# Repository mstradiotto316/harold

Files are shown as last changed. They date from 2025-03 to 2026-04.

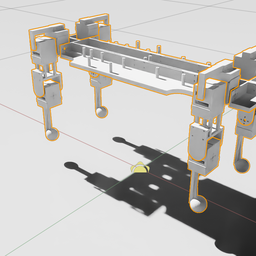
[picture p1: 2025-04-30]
part_files/V4/.thumbs/256x256/harold_5.usd.png

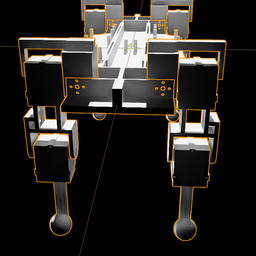
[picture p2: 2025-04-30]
part_files/V4/.thumbs/256x256/harold_2.usd.png

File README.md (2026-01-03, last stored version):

# Harold Quadruped Robot

This repository contains the code for the Harold quadruped robot, a small legged robot platform for reinforcement learning research and experimentation.

## TODO

1. Make sure the new robot meets this setup
https://docs.isaacsim.omniverse.nvidia.com/latest/isaac_lab_tutorials/tutorial_instanceable_assets.html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
2. Fix component mounts on the next iteration of the chassis
3. Set the base servo ID to 0 instead of 1 (it's too difficult to disassemble it all again to fix this)

## Isaac Sim & Isaac Lab
NOTE: This is meant to be used on Linux Ubuntu
NOTE: YOU MUST INSTALL ISAAC SIM AND ISAAC LAB FIRST
https://isaac-sim.github.io/IsaacLab/main/source/setup/installation/binaries_installation.html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

1. Make sure you install the project:
    python -m pip install -e harold_isaac_lab/source/harold_isaac_lab

2. To see the available tasks use:
    python harold_isaac_lab/scripts/list_envs.py

3. To run training (recommended):
    activate the virtual environment:
    source ~/Desktop/env_isaaclab/bin/activate

    run the default flat-terrain training:
    python scripts/harold.py train

    optional task selection:
    python scripts/harold.py train --task rough

    optional mode selection:
    python scripts/harold.py train --mode scripted

    advanced/manual (avoid for agents):
    python harold_isaac_lab/scripts/skrl/train.py --task=Template-Harold-Direct-flat-terrain-v0 --num_envs 8192 --headless --video --video_length 250 --video_interval 3200

4. Launch Tensorboard to view training progress:
python3 -m tensorboard.main --logdir logs/

## Repository Structure 

- `firmware/`: Arduino code for the robot
  - `robot_controller/`: Main servo controller for the robot
  - `servo_calibration/`: Servo calibration utility
  - `joint_test/`: Test individual robot joints

- `policy/`: Neural network policy for robot control
  - `harold_policy.onnx`: ONNX model for the control policy
  - `action_config.pt`: Configuration for action scaling
  - `observations_playback_test.py`: Test policy with recorded observations

- `sensors/`: Code for interfacing with sensors
  - `imu_reader.py`: Class for MPU6050 IMU sensor integration
  - `smbus_example.py`: Example for I2C communication

- `tools/`: Utility scripts
  - `verify_policy.py`: Verify the ONNX policy model
  - `test_imu.py`: Test the IMU sensor
  - `edit_action_config.py`: Tool to edit action configuration

- `simulation_files/` & `pushup_simulation_files/`: Simulation environments
  - Contains simulation code for training and testing the robot

- `simulation_logs/`: Log files from simulation for playback testing
  - `observations.log`: Recorded sensor observations
  - `actions.log`: Recorded policy actions
  - `processed_actions.log`: Actions processed for deployment

## Hardware Components

### Computing
- **Jetson Nano**: Main computing platform running the neural network policy
  - Communicates with IMU via I2C bus 1
  - Connects to Arduino via USB (typically /dev/ttyACM0)

### Sensors
- **MPU6050 IMU**: 6-axis inertial measurement unit
  - I2C address: 0x68
  - Provides acceleration and gyroscope measurements
  - Connected to I2C bus 1 on Jetson Nano

### Actuators
- **ESP32 Servo Controller**: Motor controller board
  - Serial communication at 115200 baud rate
  - Runs control loop at 200Hz (5ms intervals)

- **FeeTech STS3215 Servo Motors**: For quadruped locomotion
  - 3 servos per leg (shoulder, thigh, calf)
  - Safety features include emergency shutdown and position limits

## Joint Configuration

The robot's joint configuration matches the simulation directly:

1. **Joint Order**:
   - 0: Front Left Shoulder
   - 1: Front Right Shoulder
   - 2: Back Left Shoulder
   - 3: Back Right Shoulder
   - 4: Front Left Thigh
   - 5: Front Right Thigh
   - 6: Back Left Thigh
   - 7: Back Right Thigh
   - 8: Front Left Knee
   - 9: Front Right Knee
   - 10: Back Left Knee
   - 11: Back Right Knee

2. **Servo Direction**:
   - Shoulders: Positive positions move upward from center, negative positions move downward
   - Thighs and Knees: Positive positions move toward the front of the robot, negative positions move toward the rear

This configuration ensures that the real robot's movements directly correspond to the simulation, with no need for joint remapping or direction inversions.

## Development Environment

### Arduino IDE

Due to limitations on the Jetson Nano, we are forced to use an older ARM specific version of the Arduino software:

*   Legacy IDE (1.8.19) Linux Arm 64 Bit

**Important Notes for this Arduino Environment:**

*   **Unavailable Functions:** Be aware that some standard C/C++ library functions might be missing. For example, `strtof` (string-to-float with error checking) is unavailable. Use alternatives like `atof` (standard C string-to-float), keeping in mind its limitations (e.g., less robust error reporting).
*   **Code Structure:** This environment may be stricter regarding code structure than newer IDEs. To avoid `"not declared in this scope"` errors, ensure proper C/C++ ordering: Place all `#include` directives, `#define` constants, global variable declarations, and forward function declarations (prototypes) *before* the `setup()` and `loop()` functions. Define helper functions *after* `loop()`. Do not rely solely on the IDE's automatic function prototyping.

## Usage

### Running with Live IMU Data

To run the robot with live IMU sensor data:

```bash
python3 policy/robot_controller.py [--serial_port PORT]
```

### Running with Recorded Observations

To run the robot using pre-recorded observation logs from simulation:

```bash
python3 policy/observations_playback_test.py [--obs_log_file PATH] [--serial_port PORT] [--loop]
```

Options:
- `--obs_log_file PATH`: Specify a custom observation log file (default: simulation_logs/observations.log)
- `--serial_port PORT`: Specify a custom serial port (default: /dev/ttyACM0)
- `--loop`: Continuously loop the observation log file

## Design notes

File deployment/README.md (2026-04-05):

# Harold Deployment - Raspberry Pi 5

Real-time inference for Harold quadruped robot using either open-loop CPG or direct RL policy control.

## Architecture

```
RPi 5 (inference + CPG) <--USB Serial 115200--> ESP32 (servo control) <--1Mbps--> 12 Servos
         |
         | I2C
         v
     MPU6050 (IMU)
```

## Quick Start

```bash
# Install dependencies
pip install -r requirements.txt

# Run controller (robot must be connected)
python inference/harold_controller.py
```

## Components

| Component | Description |
|---|---|
| `policy/harold_policy.onnx` | Exported neural network (48D -> 12D) |
| `policy/policy_metadata.json` | Normalization stats + joint config |
| `inference/harold_controller.py` | Main 20 Hz control loop |
| `inference/cpg_generator.py` | CPG trajectory generator |
| `common/cpg_math.py` | Shared CPG math kernel (sim + hardware) |
| `inference/observation_builder.py` | IMU + servo -> 48D observation |
| `inference/action_converter.py` | Policy output -> servo commands |
| `drivers/imu_reader_rpi5.py` | MPU6050 I2C driver |
| `drivers/esp32_serial.py` | ESP32 serial wrapper |

## Control Loop (20 Hz)

1. Compute CPG base trajectory from time (CPG-only mode)
2. Build 48D observation from IMU + servo feedback (policy mode)
3. Run ONNX inference -> 12D action (policy mode)
4. Convert targets to hardware convention
5. Send to ESP32 via serial

## Safety Features

- 250ms watchdog timeout
- Joint angle limits (conservative)
- Load monitoring (>90% = emergency stop)
- Keyboard interrupt = safe stance

## Configuration

- `config/hardware.yaml` - Servo IDs, signs, limits
- `config/cpg.yaml` - CPG parameters (matches simulation)
- `config/stance.yaml` - Canonical ready stance (shared across hardware + sim)

Note: `policy/policy_metadata.json` captures training-time defaults; do not edit it for stance changes.

### Joint Sign Convention

- Shoulders are not mirrored at the high-level command/observation layer. Positive shoulder motion should mean the same thing on every leg.
- Thighs and calves are inverted between RL convention and hardware convention.
- Right-side servo mirroring is handled by `config/hardware.yaml` `direction` and the ESP32 firmware `DIR_TABLE`, not by flipping shoulder `joint_sign`.
- `inference.harold_controller` rejects startup if exported metadata `joint_sign` does not match `config/hardware.yaml`.

## Testing

```bash
# Test IMU
python tests/test_imu.py

# Test ESP32 communication
python tests/test_esp32.py

# Test inference (no hardware)
python tests/test_inference.py
```

## Diagnostics

- Session CSVs now flush every row by default to survive abrupt resets.
- Controller exceptions write to `logs/controller_diagnostics.log` with throttling + USB state.
- To persist system logs across reboots, run `scripts/enable_persistent_journal.sh` on the Pi (requires sudo).

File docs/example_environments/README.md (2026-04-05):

# Isaac Lab Example Environments

Technical breakdowns of every quadruped locomotion environment in Isaac Lab. Each document covers the robot specs, observation/action spaces, full reward structure with weights, command ranges, domain randomization, training config, and relevance to Harold.

These are reference implementations that Harold's training is based on. Use them to compare reward terms, thresholds, and scaling when debugging or tuning Harold's config.

## Manager-Based Environments

| Robot | Terrain | File | Gym ID |
|---|---|---|---|
| Boston Dynamics Spot | Flat | [spot_flat.md](spot_flat.md) | `Isaac-Velocity-Flat-Spot-v0` |
| Unitree Go2 | Flat | [go2_flat.md](go2_flat.md) | `Isaac-Velocity-Flat-Unitree-Go2-v0` |
| Unitree Go2 | Rough | [go2_rough.md](go2_rough.md) | `Isaac-Velocity-Rough-Unitree-Go2-v0` |
| Unitree Go1 | Flat | [go1_flat.md](go1_flat.md) | `Isaac-Velocity-Flat-Unitree-Go1-v0` |
| Unitree Go1 | Rough | [go1_rough.md](go1_rough.md) | `Isaac-Velocity-Rough-Unitree-Go1-v0` |
| Unitree A1 | Flat | [a1_flat.md](a1_flat.md) | `Isaac-Velocity-Flat-Unitree-A1-v0` |
| ANYbotics ANYmal D | Flat | [anymal_d_flat.md](anymal_d_flat.md) | `Isaac-Velocity-Flat-Anymal-D-v0` |
| ANYbotics ANYmal D | Rough | [anymal_d_rough.md](anymal_d_rough.md) | `Isaac-Velocity-Rough-Anymal-D-v0` |
| ANYbotics ANYmal B | Flat | [anymal_b_flat.md](anymal_b_flat.md) | `Isaac-Velocity-Flat-Anymal-B-v0` |
| ANYbotics ANYmal B | Rough | [anymal_b_rough.md](anymal_b_rough.md) | `Isaac-Velocity-Rough-Anymal-B-v0` |

## Direct Environments

| Robot | Terrain | File | Gym ID |
|---|---|---|---|
| ANYbotics ANYmal C | Flat/Rough | [anymal_c_direct.md](anymal_c_direct.md) | `Isaac-Velocity-Flat-Anymal-C-Direct-v0` |

**ANYmal C Direct is the most relevant reference for Harold** — it uses the same direct environment architecture (not manager-based) and reveals important porting considerations like manual `step_dt` multiplication on rewards.

## Robot Size Comparison

| Robot | Mass | Leg Length | DOF | Notes |
|---|---|---|-----|---|
| **Harold** | **2 kg** | **~0.15 m** | **12** | **Our robot** |
| Unitree A1 | ~12 kg | ~0.25 m | 12 | Closest in size |
| Unitree Go1 | ~12 kg | ~0.25 m | 12 | Similar to A1 |
| Unitree Go2 | ~15 kg | ~0.3 m | 12 | Mid-size |
| BD Spot | ~32 kg | ~0.5 m | 12 | Our reward source |
| ANYmal B | ~30 kg | ~0.4 m | 12 | Large |
| ANYmal C | ~50 kg | ~0.55 m | 12 | Large, direct env |
| ANYmal D | ~50 kg | ~0.55 m | 12 | Large |

Harold is significantly smaller than all reference robots. Key scaling considerations:
- **Velocity commands**: Scale down proportionally to leg length (Froude scaling)
- **Velocity thresholds**: Must be lowered for Harold's achievable speeds
- **Air time / gait cadence**: Smaller animals step faster
- **Foot clearance**: Scale to ~20% of leg length
- **Domain randomization**: Mass perturbations, push forces, etc. must be proportional to body mass
- **Reward weights**: Torque and force penalties may need rebalancing for smaller actuators

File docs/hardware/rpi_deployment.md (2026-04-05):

# Harold Deployment - Raspberry Pi 5

Real-time inference for Harold quadruped robot (open-loop CPG or direct RL policy depending on mode).

## Architecture

```
RPi 5 (inference + CPG) <--USB Serial 115200--> ESP32 (servo control) <--1Mbps--> 12 Servos
         |
         | I2C
         v
     MPU6050 (IMU)
```

## Quick Start

Use system `python3` on the Pi (no virtualenv required).

```bash
# Install dependencies
python3 -m pip install -r deployment/requirements.txt

# Run controller (robot must be connected)
python3 -m inference.harold_controller
```

## Syncing Runtime from Desktop

The Pi runtime is a git checkout of this repo. Sync from the desktop before hardware tests:

```bash
# On the desktop after edits
git add -A
git commit -m "Describe changes"
git push

# On the Pi before tests
git status -sb     # must be clean
git pull --ff-only
```

Avoid editing runtime code on the Pi. If a hotfix is unavoidable, commit it on the Pi,
push, and then pull it on the desktop to keep both repos in sync.

## Components

Paths below are relative to the deployment root (typically `<repo-root>/deployment`, e.g. `/home/pi/harold/deployment`).

| Component | Description |
|---|---|
| `policy/harold_policy.onnx` | Exported neural network (observation -> 12D actions) |
| `policy/policy_metadata.json` | Normalization stats + joint config (if applicable) |
| `inference/harold_controller.py` | Main policy-rate control loop |
| `inference/cpg_generator.py` | CPG trajectory generator |
| `common/cpg_math.py` | Shared CPG math kernel (sim + hardware) |
| `inference/observation_builder.py` | IMU + servo -> 48D observation |
| `inference/action_converter.py` | Policy output -> servo commands |
| `drivers/imu_reader_rpi5.py` | MPU6050 I2C driver |
| `drivers/esp32_serial.py` | ESP32 serial wrapper |

## Control Loop (policy rate)

1. Compute CPG base trajectory from time (CPG-only mode)
2. Build 48D observation from IMU + servo feedback (policy mode)
3. Run ONNX inference (normalization may be baked into the export; verify before adding preprocessing)
4. Convert targets to hardware convention
5. Send to ESP32 via serial

## Safety Features

- Watchdog timeout (configured in firmware)
- Joint angle limits (conservative, configured in runtime)
- Load monitoring with emergency stop (threshold configured in runtime)
- Keyboard interrupt = safe stance

## Configuration

- `config/hardware.yaml` - Servo IDs, signs, limits
- `config/cpg.yaml` - CPG parameters (matches simulation)
- `config/stance.yaml` - Canonical ready stance (shared across hardware + sim)

Note: `policy/policy_metadata.json` captures training-time defaults; do not edit it for stance changes.

### Joint Sign Convention

- High-level shoulder semantics are the same on all four legs. Do not mirror FR/BR shoulders in policy space.
- Thigh and calf joints are sign-inverted between RL convention and hardware convention.
- Right-side servo mounting is handled separately by `config/hardware.yaml` `direction` values and the ESP32 firmware `DIR_TABLE`.
- Controller startup treats `config/hardware.yaml` as the source of truth and rejects exported metadata whose `joint_sign` disagrees with it.

## Testing

```bash
# Test IMU
python tests/test_imu.py

# Test ESP32 communication
python tests/test_esp32.py

# Test inference (no hardware)
python tests/test_inference.py
```

## Diagnostics

- Session CSVs now flush every row by default to survive abrupt resets.
- Controller exceptions write to `logs/controller_diagnostics.log` with throttling + USB state.
- To persist system logs across reboots, run `scripts/enable_persistent_journal.sh` on the Pi (requires sudo).

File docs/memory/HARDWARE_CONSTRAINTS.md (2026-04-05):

# Hardware Constraints for Sim-to-Real Transfer

## Purpose

This document provides **REAL-WORLD CONSTRAINTS** that experimentation agents MUST consider when proposing configuration changes. Simulation parameters should remain within these bounds for successful hardware deployment.

**Read this before modifying**: `effort_limit`, `stiffness`, `damping`, joint limits, or control rates.

---

## Servo Specifications (FeeTech ST3215)

Source: `docs/hardware/servos/ST3215_Servo.pdf`, `docs/hardware/servos/Communication_Protocol_User_Manual_EN.pdf`

### Torque & Power

| Parameter | Real Hardware | Simulation | Status |
|---|---|---|---|
| **Max Torque** | 30 kg·cm (2.94 Nm) @12V | 2.8 Nm | 95% of max |
| Idle Current | 180 mA | N/A | - |
| Stall Current | 2.7 A | N/A | - |
| Voltage | 6-12.6V (12V recommended) | N/A | - |

**Note**: Simulation uses 2.8 Nm effort limit (95% of hardware max). Session 21 discovered that stiffness (not just effort limit) was the critical factor - increased from 200 to 1200 for realistic servo tracking.

### Position & Speed

| Parameter | Real Hardware | Simulation | Status |
|---|---|---|---|
| Resolution | 4096 steps/360° (0.088°/step) | Continuous | OK |
| Max Speed | 45 RPM (270°/s = 4.71 rad/s) @12V | Limited by PD | Verify on hardware |
| Control Rate | Position commands @1 Mbps bus | 20 Hz policy | OK |

### Joint Limits (Mechanical)

| Joint | Min | Max | Simulation | Status |
|---|-----|-----|---|---|
| Shoulders | -30° (-0.5236 rad) | +30° (+0.5236 rad) | ±0.5236 rad | Matched |
| Thighs | -90° (-1.5708 rad) | +90° (+1.5708 rad) | ±1.5708 rad | Matched |
| Calves | -90° (-1.5708 rad) | +90° (+1.5708 rad) | ±1.5708 rad | Matched |

**WARNING**: Joint limits are mechanical stops. Exceeding them in sim will not transfer to hardware - the servo will hit physical limits and potentially damage the robot.

---

## Controller (ESP32)

| Parameter | Value | Notes |
|---|---|---|
| Control loop | ~200 Hz | 5 ms intervals |
| Servo bus | Serial1 @ 1 Mbps | TTL half-duplex |
| USB telemetry | 115200 baud | To host PC |
| Watchdog | 250 ms timeout | E-stop on timeout |

---

## IMU (MPU6050)

| Parameter | Value | Notes |
|---|---|---|
| Type | 6-axis (3 accel + 3 gyro) | |
| I2C address | 0x68 | |
| Sample rate | Up to 200 Hz | Matches control loop |
| Noise (angular velocity) | ~0.01 rad/s | Sim uses this for DR |
| Noise (gravity projection) | ~0.05 | Sim uses this for DR |

---

## Physical Robot

| Parameter | Value | Source |
|---|---|---|
| Total mass | ~2.0 kg | Measured |
| Body dimensions | ~20×15×8 cm | CAD model |
| Ground clearance (standing) | ~18 cm | Measured |
| Spawn height (sim) | 0.24 m | harold.py config |
| Target height (walking) | 0.275 m | GaitCfg |

---

## Safe Parameter Ranges for Experiments

### DO NOT EXCEED (Hardware Limits)

| Parameter | Current | Max Safe | Reason |
|---|---|---|---|
| `effort_limit` | 2.8 Nm | 2.94 Nm | Currently at 95% of hardware max |
| `stiffness` | 1200 | TBD | Session 21: Higher values needed for sim accuracy |
| `damping` | 50 | TBD | Session 21: Lower ratio for responsiveness |
| `action_scale` | 0.5 | 1.0 | Larger may hit joint limits with some poses |

**Session 21 Discovery**: Original stiffness=200 was FAR too low. Servos couldn't extend legs under load. Real robot does pushups fine, so sim was inaccurate. Stiffness=1200 with damping=50 matches real servo behavior. Sim-to-real testing needed to validate these values on hardware.

### MUST PRESERVE (Sim-to-Real Critical)

| Parameter | Required Value | Reason |
|---|---|---|
| Joint limits (shoulders) | ±30° (±0.5236 rad) | Mechanical stops |
| Joint limits (thighs/calves) | ±90° (±1.5708 rad) | Mechanical stops |
| Control rate | 20 Hz policy | Matches deployment pipeline |
| Joint order | [FL, FR, BL, BR] × [shoulder, thigh, calf] | Matches firmware |
| Sign convention | Thighs/calves inverted | See `action_config.json` |

### MAY TUNE FREELY (No Hardware Impact)

| Parameter | Typical Range | Notes |
|---|---|---|
| Reward weights | Any | Pure learning signal |
| `action_filter_beta` | 0.1-0.5 | Smoothing preference |
| Termination thresholds | Any | Training curriculum |
| Domain randomization ranges | Any | Robustness tuning |
| `height_reward`, `forward_reward` etc. | Any | Reward shaping |
| `low_height_penalty`, `low_height_threshold` | Any | Training signal |

---

## Servo Communication Protocol

From `docs/hardware/servos/Communication_Protocol_User_Manual_EN.pdf`:

- **Packet format**: `0xFF 0xFF` + ID + Length + Instruction + Parameters + Checksum
- **ID range**: 0-253 (Harold uses IDs 1-12)
- **Broadcast ID**: 254 (0xFE) for simultaneous control
- **Instructions**: PING (0x01), READ (0x02), WRITE (0x03), SYNC WRITE (0x83)
- **Feedback available**: Position, Speed, Load, Voltage, Temperature, Current

---

## Deployment Mapping

### Joint Order (RL → Firmware)

```
RL Policy Output:  [FL_sh, FR_sh, BL_sh, BR_sh, FL_th, FR_th, BL_th, BR_th, FL_ca, FR_ca, BL_ca, BR_ca]
Servo IDs:         [1,     4,     7,     10,    2,     5,     8,     11,    3,     6,     9,     12]
```

### Sign Convention

| Joint Type | RL → Hardware | Notes |
|---|---|---|
| Shoulders | +1.0 (same) | Direct mapping |
| Thighs | -1.0 (inverted) | Servo mounting |
| Calves | -1.0 (inverted) | Servo mounting |

### Position Conversion

```
servo_units = 2047 + direction * (degrees * 4096 / 360)
```

Where `direction` is +1 or -1 per the sign convention table.

---

## Servo Control Registers (ST3215)

### Critical for Backlash Mitigation

| Register | Address | Purpose | Optimal Value | Notes |
|---|---|---|---|---|
| **ACC** | 41 | Acceleration profile | **150** | 0=slowest (soft), 150=fastest (instant) |
| TORQUE_ENABLE | 40 | Enable torque | 1 | 0=limp, 1=active |
| MODE | 33 | Operating mode | 0 | 0=servo (position), 1=motor (velocity) |
| CW_DEAD | 26 | Clockwise dead zone | 1 | Minimum possible |
| CCW_DEAD | 27 | Counter-clockwise dead zone | 1 | Minimum possible |

**CRITICAL**: The ST3215's "built-in acceleration start-stop function makes the action softer" (from datasheet). For backlash systems, this is WRONG - we want **maximum acceleration** (ACC=150) for instant "bang-bang" control to cross the dead zone as fast as possible.

### WritePosEx Parameters

```cpp
st.WritePosEx(ID, Position, Speed, ACC);
// Speed: 0 = max speed (no limit), higher = specific speed in steps/sec
// ACC: 0 = slowest (soft ramp), 150 = fastest (instant)
```

---

## Training Workstation

| Component | Spec |
|---|---|
| GPU | NVIDIA GeForce RTX 4080 (16 GB VRAM) |
| RAM | 63 GB |
| CPU | Intel Core i7-8700K @ 3.70GHz |

### Training Throughput (benchmarked 2026-03-19)

**Two-phase approach**: Training runs without video at high envs; video captured post-hoc via `harold record` (~30-45s from best checkpoint at 1 env). This removes video as the RAM bottleneck.

| Envs | it/s | Samples/s | GPU | RAM | Status |
|---|---|---|-----|-----|---|
|  1024 | 18.1 | 0.45M |  6.2 GB |  8.6 GB | OK |
|  4096 | 16.0 | 1.58M |  7.2 GB |  9.3 GB | OK |
|  8192 | 11.5 | 2.26M |  8.3 GB | 10.3 GB | OK |
| 16384 |  7.3 | 2.88M | 10.3 GB | 12.3 GB | Direct-env only (standing trap at this scale) |
| 24576 |  5.4 | 3.18M | 12.3 GB | 14.6 GB | Direct-env only |

**Default: 2048 envs** (manager-based). OOMs at 4096 with ManagerBasedRLEnv on RTX 4080. Benchmark above is for direct-env (deprecated).

---

## References

- Servo datasheet: `docs/hardware/servos/ST3215_Servo.pdf`
- Communication protocol: `docs/hardware/servos/Communication_Protocol_User_Manual_EN.pdf`
- Register map: `docs/hardware/servos/ST3215_memory_register_map_EN.xls`
- Calibration guide: `docs/hardware/calibration_checklist.md`
- Deployment runtime: `docs/hardware/rpi_deployment.md`
- Action config: `deployment_artifacts/terrain_62/action_config.json`

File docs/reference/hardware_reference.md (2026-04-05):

# Hardware Reference (Robot + RPi)

This file is a technical reference for hardware operation. Use `AGENTS.md` for workflows and `docs/memory/CONTEXT.md` for current network details.

## Core hardware stack

- Raspberry Pi 5 runs policy inference and the 20 Hz control loop.
- ESP32 handles the servo bus control loop and safety watchdog.
- FeeTech STS3215 servos provide joint actuation.
- MPU6050 IMU provides inertial measurements.

For exact limits, servo specs, and safe ranges, see `docs/memory/HARDWARE_CONSTRAINTS.md`.

## Runtime layout (RPi)

Confirm repo and runtime paths in `docs/memory/CONTEXT.md` before running commands.
Runtime root is the repo’s `deployment/` directory (e.g. `/home/pi/harold/deployment`).

- Repo path (git checkout): see `docs/memory/CONTEXT.md`
- Runtime root: `<runtime-root>` (see `docs/memory/CONTEXT.md`)
- Main controller: `<runtime-root>/inference/harold_controller.py`
- Policy: `<runtime-root>/policy/harold_policy.onnx`
- Configs: `<runtime-root>/config/`
- Logs: `<runtime-root>/logs/`

## Syncing code to the Pi

The Pi runtime is a git checkout of this repo. Sync from the desktop with:

```bash
# On the desktop after edits
git add -A
git commit -m "Describe changes"
git push

# On the Pi before tests
git status -sb     # must be clean
git pull --ff-only
```

Do not edit runtime code directly on the Pi. If a hotfix is unavoidable, commit it on the Pi,
push, and then pull it on the desktop to keep both repos in sync.

## SSH access

Network addresses and credentials are tracked in `docs/memory/CONTEXT.md`.

```bash
ssh pi@<ip-or-host>
```

## Network configuration

Current IPs, hostnames, and WiFi details are maintained in `docs/memory/CONTEXT.md`.

## Service management (RPi)

```bash
sudo systemctl status harold
sudo systemctl restart harold
sudo systemctl stop harold
sudo systemctl start harold
sudo systemctl disable harold
sudo systemctl enable harold
```

## Manual controller run (RPi)

Use system `python3` on the Pi (no virtualenv required).

```bash
# Stop the service first
sudo systemctl stop harold

# Run controller manually
cd <runtime-root>
python3 -m inference.harold_controller
```

For CPG-only or scripted gait tests, see `AGENTS.md` and `docs/memory/NEXT_STEPS.md`.

## Firmware flashing (ESP32)

The ESP32 must run the streaming control firmware for the Pi to communicate with it.

```bash
# Install arduino-cli (one-time)
curl -fsSL https://raw.githubusercontent.com/arduino/arduino-cli/master/install.sh | sh
export PATH=$PATH:/home/pi/bin
arduino-cli core install esp32:esp32

# Compile and upload (use your repo path on the Pi)
cd <repo-path>
arduino-cli compile --fqbn esp32:esp32:esp32 firmware/StreamingControl/HaroldStreamingControl
arduino-cli upload -p /dev/ttyUSB0 --fqbn esp32:esp32:esp32 firmware/StreamingControl/HaroldStreamingControl
```

## Required ESP32 firmware

- `firmware/StreamingControl/HaroldStreamingControl/` (required for Pi control)
- `firmware/scripted_gait_test_1/` (standalone scripted gait)

## Hardware connections

- ESP32 via USB (CP2102 adapter) -> `/dev/ttyUSB0` (verify on the Pi)
- IMU (MPU6050) via I2C bus 1, address `0x68`

## Joint sign semantics

- Policy/RL joint order is `[FL, FR, BL, BR] x [shoulder, thigh, calf]`.
- Shoulders keep the same semantic sign on all four legs. Positive shoulder motion should mean the same body-relative motion on left and right legs.
- Thighs and calves are sign-inverted between RL convention and hardware convention.
- Right-side servo mirroring is handled by the low-level direction tables in `deployment/config/hardware.yaml` and the ESP32 firmware, not by flipping the high-level shoulder sign convention.
- If `policy/policy_metadata.json` and `deployment/config/hardware.yaml` disagree on `joint_sign`, treat that as a deployment error and regenerate/reconcile before running the controller.

## Troubleshooting

```bash
lsusb
ls /dev/ttyUSB*
dmesg | tail -20
```

If `/dev/ttyUSB0` permission errors occur:

```bash
sudo usermod -a -G dialout pi
```

For service logs and controller exceptions, see `<runtime-root>/logs/` and `docs/hardware/rpi_deployment.md`.

## Additional references

- Deployment runtime details: `docs/hardware/rpi_deployment.md`
- Servo calibration workflow: `docs/hardware/calibration_checklist.md`
- Servo datasheets and protocol: `docs/hardware/servos/`
- Hardware limits: `docs/memory/HARDWARE_CONSTRAINTS.md`
- ST3215 register map: `docs/hardware/servos/ST3215_memory_register_map_EN.xls`
- SCServo library (vendor drop): `firmware/third_party/SCServo`

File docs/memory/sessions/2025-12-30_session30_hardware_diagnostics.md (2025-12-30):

# Session 30: Hardware Diagnostics & Policy Deployment Fixes

**Date**: 2025-12-30
**Platform**: Raspberry Pi 5 (onboard robot computer)
**Focus**: Diagnosing sluggish gait + fixing policy deployment issues

## Session Summary

User reported robot seems "sluggish and weak" when running the gait routine. Through systematic debugging, we discovered:
1. Power/voltage is NOT the issue (12.1V stable)
2. Servo load was misinterpreted (display bug - divide by 10)
3. Servo speed was too slow (fixed: 1600 → 2800)
4. CPG trajectory has minimal foot lift (~1.5cm)
5. **Critical policy deployment bugs** causing policy to fail

## Key Findings

### 1. Voltage & Load Analysis

**Voltage**: Rock solid at 12.0-12.1V throughout all tests. Power supply is NOT the issue.

**Load Readings Bug**: Original script showed "200% load" but this was a display bug. The servo load register returns -1000 to +1000 (where 1000 = 100%). Fixed by dividing by 10.

**Actual Load**:
- Suspended: 8-18% (barely working)
- Ground @ 0.5Hz: 15-26% (light load)
- Ground @ 2.0Hz: 20-43% (still comfortable)

### 2. Servo Speed Fix

**Problem**: SERVO_SPEED=1600 (~140°/sec) was too slow for servos to track CPG trajectory.

**Fix**: Increased to SERVO_SPEED=2800 (~246°/sec, 91% of max).

**Result**: Feet now lift properly during swing phase instead of dragging.

### 3. CPG Trajectory Analysis

The CPG has only ~1.5cm theoretical foot lift due to:
- swing_calf: -1.40 rad (80.2°) hitting firmware limit of 80°
- Conservative thigh angles

Could improve with more aggressive swing trajectory, but firmware limits collision safety.

### 4. Policy Deployment Bugs (CRITICAL)

Found and fixed **three major bugs** preventing policy from working:

#### Bug 1: Wrong Default Pose in Observation Builder
```python
# WRONG (was using):
default_pose = [0.0, 0.0, 0.0, 0.0,        # Shoulders
                0.3, 0.3, 0.3, 0.3,        # Thighs
                -0.75, -0.75, -0.75, -0.75] # Calves

# CORRECT (simulation uses):
default_pose = [0.20, -0.20, 0.20, -0.20,   # Shoulders: alternating
                0.70, 0.70, 0.70, 0.70,     # Thighs: 0.70 rad
                -1.40, -1.40, -1.40, -1.40] # Calves: -1.40 rad
```

This caused massive observation mismatch - normalized values were hitting ±5.0 clip limits.

#### Bug 2: Wrong Default Pose in Action Converter
Same issue - action converter also had wrong default pose.

#### Bug 3: Wrong Joint Limits in Action Converter
```python
# Limits were in HARDWARE convention:
"thigh": (-55°, +5°)  # Hardware: -0.96 to +0.087 rad

# But CPG outputs RL convention:
thigh_values: 0.40 to 0.90 rad  # All POSITIVE

# Result: Thighs clamped to 0.087 rad → legs nearly straight!
```

**Fix**: Disabled redundant limits in action_converter (firmware already handles limits correctly in hardware convention).

## Files Modified

### Firmware
- `firmware/StreamingControl/HaroldStreamingControl/HaroldStreamingControl.ino`
  - Added voltage telemetry (`voltage_dV` field)
  - Increased SERVO_SPEED: 1600 → 2800

### Deployment (Python)
- `deployment/drivers/esp32_serial.py`
  - Added `voltage_dV` and `voltage_V` to Telemetry dataclass

- `deployment/inference/observation_builder.py`
  - Fixed default_pose to match simulation's athletic_pose

- `deployment/inference/action_converter.py`
  - Fixed default_pose to match simulation's athletic_pose
  - Disabled wrong joint limits (firmware handles this)

- `deployment/run_cpg_only.py`
  - Added voltage/load logging during gait

## Files Created

- `scripts/voltage_monitor.py` - Real-time voltage and load monitoring tool

## Test Results

### CPG-Only (No Policy)
- 0.5 Hz: Works, feet lift properly with SERVO_SPEED=2800
- 1.0 Hz: Works, more dynamic motion
- 1.5-2.0 Hz: Works, servos have plenty of headroom

### Policy + CPG
After fixes, policy now runs without causing legs to straighten or freeze. Shoulder positions follow CPG pattern with small policy corrections.

## Remaining Issues

1. **CPG trajectory hitch**: Calf has velocity discontinuity at stance/swing transition (phase 0.60). Could smooth this with better trajectory math.

2. **Policy behavior**: Need more testing to verify policy is actually helping vs just not hurting.

## Next Steps

1. Test policy on ground (not just suspended)
2. Compare CPG-only vs CPG+policy walking performance
3. Consider smoothing CPG calf trajectory
4. Consider training new policy with corrected deployment code

## Key Learnings

1. **Always match default poses** between simulation and deployment
2. **Joint limits must use correct convention** (RL vs hardware)
3. **Servo speed matters** for trajectory tracking
4. **Voltage monitoring** confirmed power supply is adequate
5. **Load readings need proper scaling** (÷10 for percentage)

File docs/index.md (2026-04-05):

# Documentation Index

This repository uses AGENTS.md as the primary agent quickstart. Use the role-based sections below to find detailed references under `docs/`.

## Environment Rules

- Desktop simulation and training use `/home/matteo/Desktop/env_isaaclab`.
- Raspberry Pi deployment uses system `python3` without a virtualenv.
- A plain activated desktop shell is not enough for simulator-backed imports such as `omni.*`; use `python scripts/harold.py ...` or Isaac Lab app entrypoints when those modules are involved.

## Desktop Isaac Lab experiments (training/analysis)

- `AGENTS.md` - Primary agent workflow and CLI usage.
- `docs/memory/CONTEXT.md` - Current state and goals.
- `docs/memory/NEXT_STEPS.md` - Priority queue and pending tasks.
- `docs/memory/EXPERIMENTS.md` - Experiment history.
- `docs/memory/OBSERVATIONS.md` - Curated, current insights.
- `docs/memory/archives/index.md` - Historical observations archive index (read only if needed).
- `docs/memory/OBSERVABILITY.md` - Metrics and validation protocol.
- `docs/memory/REFERENCE_ANALYSIS.md` - Isaac Lab reference analysis.
- `docs/reference/sim_reference.md` - Simulation task and config reference.
- `docs/sim/isaac_lab_extension.md` - Isaac Lab extension details.
- `docs/overview.md` - Repository overview and installation notes.

## Hardware walking tests (RPi)

- `docs/hardware/rpi_deployment.md` - RPi runtime/inference pipeline.
- `docs/hardware/calibration_checklist.md` - Servo calibration and sign checks.
- `docs/hardware/servos/` - Servo datasheets and protocol references.
- `docs/memory/HARDWARE_CONSTRAINTS.md` - Sim-to-real limits and safe ranges.
- `docs/memory/CONTEXT.md` - Current state and goals.
- `docs/memory/NEXT_STEPS.md` - Priority queue and pending tasks.
- `docs/reference/hardware_reference.md` - Joint order and hardware reference.

## Firmware, sensors, logging

- `docs/hardware/calibration_checklist.md` - Firmware calibration workflow.
- `docs/hardware/rpi_deployment.md` - Control loop, logging, and safety features.
- `docs/reference/hardware_reference.md` - Joint order, axes, and hardware specs.
- `docs/hardware/servos/` - Servo datasheets and protocol references.
- `docs/memory/OBSERVATIONS.md` - Known issues and logging insights.
- `docs/memory/archives/index.md` - Historical observations archive index.

## Autoresearch (Autonomous Experimentation)

- `docs/autoresearch/program.md` - Lab policy: experiment loop, decision rules, video review protocol.
- `docs/autoresearch/PARAMETER_REGISTRY.md` - Tunable vs frozen parameters with safe ranges.
- `scripts/autoresearch.py` - Helper functions (apply/revert/score/log).

## Skills

- `docs/skills/video_annotation.md` - Video annotation skill: frame-by-frame analysis of RL training footage using multimodal vision.

## Shared references

- `docs/kinematics/harold_8_kinematics.yaml` - USD-derived joint/mesh kinematics spec.
- `deployment/config/stance.yaml` - Canonical ready stance for hardware + sim.

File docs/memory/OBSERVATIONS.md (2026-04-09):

# Harold Observations & Insights

## 2026-04-07/08: Servo drift DR + reward optimization — 9 KEEPs/6 DISCARDs, reward 805.9

**Servo drift DR validated free (±0.05 to ±0.15), angular velocity + gait tuning pushed to 805.9. 15 experiments, config converged.**

Key findings:
- **Servo drift DR completely free**: ±0.05, ±0.08, ±0.10, ±0.15 rad = identical reward (~724). Settled ±0.10 for deployment.
- **Fast vs standard training**: Fast with DR costs ~7%. Standard fully recovers. DR needs longer training.
- **angular_velocity_weight 4→5→6**: All KEEP, +55% yaw. 7 DISCARD (zero-sum with velocity).
- **gait_weight 12→14**: KEEP (+6.3%, velocity also improved). 16 borderline — reward inflation trap.
- **Weight inflation dead end**: gait 16, velocity 27 produced high rewards but video showed DEGENERATE. Trust video, not reward numbers.
- **air_time 8→10**: DEGENERATE (orientation 64% worse, instability from over-lifting).
- **Seed-robust**: seed 123 vs 42 = -1.4% variance, LOCOMOTION confirmed.
- **Dead ends**: foot_clearance 1.5 (-2.5%), mini_batches 6 (identical to 4).
- **4 consecutive DISCARDs** after EXP-948 confirm config convergence.

Deployment candidate: EXP-948 (reward 805.9, vel 23.04, yaw 5.34, drift ±0.10)
Config: vel=25, gait=14, angular=6, air_time=8, clearance=1.0, orient=-3.0, joint_pos=-0.7, motion=-0.5, smoothness=-0.5, action_scale=0.4, servo_drift=0.10

## 2026-04-05/06: Sim-to-real DR + reward scaling — 15 KEEPs, reward 854.6 (deploy) / 910.3 (sim max)

**Hardware-informed DR + positive reward weight scaling pushed Harold from EXP-875 (reward=701.4) to EXP-921 (reward=854.6, +21.8% deploy candidate) and EXP-923 (reward=910.3, +29.8% sim max) with much harder DR. 38 experiments, 15 KEEPs.**

Key findings:
- **Phase 1+2 DR only costs 2.9%**: Stronger pushes (Y±0.6), external forces (±2N), wider friction (0.2-1.2), obs noise (±0.08) — only dropped reward from 701.4 to 681.2.
- **joint_torques_weight -5e-4→-2e-3**: 4x increase, only -1.8% reward. Torque penalty 5.5x higher — directly reduces peak servo load on hardware.
- **base_motion_weight -2.0→-1.5**: Freed motion budget improved orientation 16% and air time 4.4%. Policy uses dynamic recovery motions.
- **air_time_weight 12→14**: +17% air time, +3.7% reward. Better foot clearance for carpet deployment.
- **gait_weight 18→20**: +11.2% gait quality. Cleaner diagonal trot provides lateral stability on hardware.
- **velocity_weight 12→14**: +18% velocity tracking, +5.9% reward. Faster forward motion resists lateral drift.
- **angular_velocity_weight 7→8**: +13.4% yaw tracking, +1.5% reward. Better turning on hardware.
- **entropy 0.01→0.005**: +1.4% reward. More exploitation with well-explored reward landscape.
- **30-min training (EXP-904)**: +3.5% reward over 15 min. No degeneration with balanced reward weights.
- **60-min training (EXP-905)**: +1.9% further. Gait 18.04/20 (near max), air_time 6.09 (best ever). No belly-shuffling — balanced rewards prevent degeneration that plagued old config.
- **DISCARD insights**: smoothness -1.5 (over-penalized), foot_slip -0.5 (crouched stance), episode_length 30s (no benefit), learning_epochs 12 (overfit), clearance_weight 4 (orientation 2x worse), shaper 0.25 (orientation regression), clearance_target 0.08 (negligible benefit)
- **Seed-robust**: seed 123 produces 756.6 vs seed 42's 752.6 (+0.5%) — config generalizes
- **Clearance+orientation combo (EXP-918)**: clearance 3.5 + orientation -5.5 = reward 795.5. User's TensorBoard min-reward spike observation correctly predicted convergence after early stop.
- **gait_weight 22 (EXP-919)**: +10% gait quality but -30% orientation. Forward pitch is structural to strong gait enforcement.
- **velocity_weight 16 (EXP-921)**: BREAKTHROUGH — reward 854.6, velocity +13.4%, AND orientation fixed (+37%). Faster walking = better dynamic stability.
- **Orientation -6.0 paradox**: Stronger orientation penalty with gait=22 produces *worse* final orientation (-0.278 vs -0.247). The policy fights through the penalty.
- **Key insight**: Velocity is the lever that fixes orientation — not orientation penalty strength. Faster forward motion stabilizes the body dynamically.

Current best config (EXP-921, 60-min training): gait=22, vel=16, angular=8, air_time=14, clearance=3.5, joint_pos=-0.4, smoothness=-1.0, orientation=-5.5, motion=-1.5, torques=-2e-3, shaper=0.3, entropy=0.005

## 2026-04-04: Reward weight tuning + PPO — 7 KEEPs, reward 701.4

**Systematic reward weight tuning + PPO shaper pushed Harold from EXP-858 (reward=572) to EXP-875 (reward=701.4, +22.6%).**

Key findings:
- **Network capacity NOT the bottleneck**: [512,512,256] and [512,256,256,128] both no improvement (EXP-856, 857 DISCARD)
- **gait_weight 15→18**: Cleaner trot, best-ever orientation (-0.078). KEEP.
- **base_linear_velocity_weight 10→12**: +20.6% velocity tracking. KEEP.
- **joint_pos_weight -0.7→-0.4**: Raw joint deviation doubled, wider range of motion. KEEP.
- **base_angular_velocity_weight 5→7**: +42% yaw tracking, critical for deployment turning. KEEP.
- **air_time_weight 10→12**: +27.8% air time, improved stride. KEEP.
- **DISCARD insights**: air_time mode_time 0.35 (inflated metric, no visual improvement), entropy 0.02 (zero effect), lin_vel_x_max 1.5 (exceeded capability), orientation -6 (over-constraining)
- **autoresearch.py revert bug**: `revert` wipes ALL accumulated KEEPs. Must delete .autoresearch_baseline.json after each KEEP to create fresh snapshot.

- **rewards_shaper_scale 0.5→0.3**: Broke 691 plateau! Lower shaper helps PPO converge better. KEEP (EXP-875).
- **Plateau confirmed**: 20 experiments, 13 DISCARDs after EXP-875. orientation -6, mini_batches 6, foot_slip -0.5, longer training, clearance target 0.10, seed 123, variance -0.2, motion -2.5, shaper 0.25, lambda 0.97 — ALL DISCARD.
- **Seed-robust**: seed 42 and 123 both converge to ~691-701, confirming config quality.
- **Longer training degenerates**: 30 min produces belly-shuffling (reward hack, EXP-871). 15 min "fast" is optimal.
- **lambda 0.97 catastrophic**: -11% reward with robot falls. GAE lambda 0.95 is correct.

Current best config (EXP-875): gait=18, vel=12, angular=7, air_time=12, clearance=3.0, joint_pos=-0.4, smoothness=-1.0, orientation=-5.0, motion=-2.0, shaper=0.3

## 2026-03-31: Sim-to-real transfer stack — from shuffling to natural walking

**4-phase sim-to-real overhaul transformed Harold from shuffling (EXP-785: reward=340) to deployment-ready natural walking (EXP-814: reward=508, air_time=3.63).**

Key findings:
- **EMA action filtering (Phase 1)**: Training with deployment-matched action smoothing (beta=0.2) eliminated jittery micro-movements. Critical insight: train/deploy mismatch was the root cause of shuffling.
- **Observation noise as regularizer (Phase 2)**: Adding IMU/encoder noise INCREASED reward (+5.4%), not decreased. Noise prevents overfitting to precise sensor values.
- **Air time threshold was the stride-length lever (Phase 3)**: mode_time 0.15->0.25 produced +64% air time, visibly longer strides. This single change had the most impact on gait naturalness.
- **Perturbation robustness is free (Phase 4)**: Doubling push forces produced no regression — perturbations act as yet another regularizer.
- **Each phase composed well**: No negative interactions between EMA, noise, rewards, and perturbations.

Current best config (EXP-814): EMA beta=0.2, obs noise enabled, air_time mode_time=0.25, foot_clearance target=0.07 (wt=1.5), action_smoothness=-1.0, gait vel_threshold=0.3, push ±0.2 m/s.

## 2026-03-31: Compound config + PPO tuning — 4 KEEPs, reward 487.9

**Compound config combining 6 validated improvements + PPO tuning pushed Harold to reward 487.9 (+43.2% over EXP-785).**

Key findings:
- **Compound config composes well**: All 6 validated improvements (vel=8, gait=13, air=8, smooth=-0.5, clear=1.0/0.05, orient=-4, standing=0.02) composed without interference (EXP-802 KEEP, reward 470.0)
- **learning_epochs 5->8->10**: Monotonic improvement. More gradient passes per rollout improves sample efficiency (EXP-804 KEEP, EXP-805 KEEP)
- **rollouts 24->32**: Hurt performance (-4%). Slower convergence and lower final reward (EXP-803 DISCARD)
- **discount_factor 0.99->0.995**: Major regression (-12.6%). Higher gamma slows learning significantly (EXP-806 DISCARD)
- **base_angular_velocity_weight 5->8**: Reward inflation without quality improvement. All locomotion metrics regressed despite higher total reward (EXP-807 DISCARD)
- **air_time_variance_weight -1->-0.5**: Freed reward budget, especially improving orientation (-0.073, best ever). Variance was already negligible so penalty was over-constraining (EXP-808 KEEP)

Current best config: vel=8, gait=13, air=8, smooth=-0.5, clear=1.0/0.05, orient=-4, standing=0.02, learning_epochs=10, air_time_variance=-0.5

## 2026-03-30: Reward tuning session — 5 KEEPs, reward 405.5

**Systematic reward weight tuning improved Harold from baseline EXP-785 (reward=340.8) to EXP-799 (reward=405.5, +19%).**

Key findings:
- **base_linear_velocity_weight 5->8**: +55% velocity tracking (EXP-788 KEEP)
- **gait_weight 10->13**: Recovered gait quality, reward 390 (EXP-789 KEEP)
- **air_time_weight 5->8**: +70% foot lift time (EXP-790 KEEP)
- **action_smoothness_weight -1->-0.5**: Freed reward budget (EXP-791 KEEP)
- **foot_clearance target_height 0.03->0.05**: +27% foot clearance (EXP-799 KEEP, broke 7-DISCARD plateau)
- Longer training (30 min vs 15 min) produced WORSE results — policy converges to conservative stepping
- base_motion penalty reduction caused major regression — the penalty is needed to drive forward motion
- Results are seed-robust (seed=42 and seed=123 produce comparable metrics)
- Higher vel_weight=10 trades stability for speed (ep_len dropped to 992)

Current best config: vel=8, gait=13, air_time=8, smooth=-0.5, foot_clearance target_height=0.05

## 2026-03-29: BREAKTHROUGH — Harold walks in manager-based architecture

**Harold achieves near-perfect trot (gait=9.7/10) in ManagerBasedRLEnv after just 800 iterations.**

The DirectRLEnv architecture that we've been using for all experiments (sim_flat_v1, sim_flat_v2, harold_flat) has a fundamental issue that prevents walking. After exhaustive investigation (7 parallel Opus agents auditing every subsystem), the confirmed differences are:

1. **Action clamping bug (FIXED)**: Our direct env clamped actions to [-1,1] before processing. The reference ActionManager does NOT clamp. This limited joints to ±0.2 rad from default and corrupted the action smoothness penalty + last_action observation.
2. **Joint penalty scope bug (FIXED)**: Our port filtered joint_acc/joint_vel penalties to hip joints only. The Spot reference functions ignore the SceneEntityCfg joint_names filter and penalize ALL 12 joints.
3. **Unknown remaining issue**: Even after fixing both bugs, the direct env still doesn't walk (EXP-783: gait=0.14 vs reference gait=9.7). The root cause remains unidentified.

**Solution**: Created `Harold-Velocity-Flat-v0` — a manager-based environment using the proven ManagerBasedRLEnv architecture with the Spot reward structure adapted for Harold's body naming and physical scale.

Key files:
- Config: `harold_isaac_lab/.../tasks/manager_based/harold_flat/flat_env_cfg.py`
- Training: `./isaaclab.sh -p harold_isaac_lab/scripts/skrl/train.py --task Harold-Velocity-Flat-v0 --num_envs 2048 --headless`

### Manager-based Harold training metrics (step 355200, 74%):
- gait: 9.69 (near-perfect trot)
- air_time: 0.49 (feet lifting)
- base_linear_velocity: 4.26 (strong velocity tracking)
- base_angular_velocity: 4.68 (strong yaw tracking)
- reward: 349
- episode_length: 999/1000

### Reference environment documentation
Created `docs/example_environments/` with 11 technical breakdowns of every Isaac Lab quadruped locomotion example (Spot, Go1, Go2, A1, ANYmal B/C/D). The ANYmal C direct env doc is particularly relevant as it documents the `step_dt` reward multiplication pattern for direct envs.

## Pre-Breakthrough History

All direct-env observations (Sessions 46-52, 700+ experiments) are archived in
`docs/memory/archives/OBSERVATIONS_pre_manager_based.md`. Key takeaway: the DirectRLEnv
architecture has a fundamental standing trap bug that prevents walking. The manager-based
architecture solved this completely.

## Evergreen Guardrails
- Video is the primary signal for success/failure. Metrics can lie (vx from falling, ep_len from standing). Run video review after every experiment.
- Use the 5-metric protocol (episode_length, upright_mean, height_reward, body_contact_penalty, vx_w_mean) as the quantitative complement to video, not a replacement.
- "On elbows" exploit remains a risk; always check height_reward and body_contact_penalty.

## Sim-to-Real Alignment Notes
- Backlash dead zone is ~10 degrees (2026-01-03).
- Best direct-env actuator match (effort=2.8): stiffness=1200, damping=75. Manager-based uses different actuator model (Kp=40, Kd=0.5) — sim-to-real alignment will need re-validation.
- Hardware telemetry logs include `cmd_pos_*` columns for commanded vs measured comparison.
- Hardware CPG baseline: Test 3 (0.4 Hz, duty 0.5) on lower-friction surface. Logs in `logs/hardware_sessions/`.

## Hardware Session Logs
- RPi logs: `/home/pi/harold/deployment/sessions/session_YYYY-MM-DD_HH-MM-SS.csv`
- Desktop copies: `logs/hardware_sessions/session_YYYY-MM-DD_HH-MM-SS.csv`

## Archives
Historical observations are moved to `docs/memory/archives/` to keep this file short.
- `archives/OBSERVATIONS_pre_manager_based.md` — Direct-env era (Sessions 46-52, 2026-03-15 to 2026-03-28)
- `archives/OBSERVATIONS_2026-01-04_full.md` — Hardware CPG baseline

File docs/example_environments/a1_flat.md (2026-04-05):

# Isaac Lab -- Unitree A1 Flat Locomotion Environment

Technical reference extracted from source files (Isaac Lab, commit ~2026-03).

---

## 1. Overview

| Field | Value |
|---|---|
| Robot | Unitree A1 (quadruped) |
| Gym ID | `Isaac-Velocity-Flat-Unitree-A1-v0` |
| Task | Velocity tracking on flat terrain |
| Terrain | `plane` (no procedural generation, no curriculum) |
| Base class chain | `LocomotionVelocityRoughEnvCfg` -> `UnitreeA1RoughEnvCfg` -> `UnitreeA1FlatEnvCfg` |

## 2. Robot Specs

| Parameter | Value |
|---|---|
| Mass | ~12 kg (real robot spec) |
| DOF | 12 (3 per leg: hip, thigh, calf) |
| Joint names | `{FL,FR,RL,RR}_{hip,thigh,calf}_joint` |
| Actuator model | `DCMotorCfg` |
| Effort limit | 33.5 Nm |
| Saturation effort | 33.5 Nm |
| Velocity limit | 21.0 rad/s |
| PD gains | Kp = 25.0, Kd = 0.5 |
| Init height | 0.42 m |
| Init joint pos | hip L/R = +/-0.1, front thigh = 0.8, rear thigh = 1.0, calf = -1.5 (rad) |
| Soft joint limit factor | 0.9 |

## 3. Observation Space (Flat)

Height scan is **removed** for the flat variant. Observation corruption is enabled during training (additive uniform noise).

| Term | Dim | Noise range |
|---|-----|---|
| `base_lin_vel` | 3 | [-0.1, 0.1] |
| `base_ang_vel` | 3 | [-0.2, 0.2] |
| `projected_gravity` | 3 | [-0.05, 0.05] |
| `velocity_commands` | 3 | none |
| `joint_pos_rel` | 12 | [-0.01, 0.01] |
| `joint_vel_rel` | 12 | [-1.5, 1.5] |
| `last_action` | 12 | none |
| **Total** | **48** | |

## 4. Action Space

| Parameter | Value |
|---|---|
| Type | Joint position targets (offsets from default pose) |
| Dim | 12 |
| Scale | **0.25** (rough_env_cfg override; base class default is 0.5) |
| Use default offset | True (actions are relative to init joint positions) |

Control frequency: sim dt = 0.005 s, decimation = 4, so policy runs at **50 Hz**.

## 5. Reward Structure

Effective weights after the full inheritance chain (`base` -> `rough_a1` -> `flat_a1`):

| Reward term | Function | Weight | Notes |
|---|---|---|---|
| `track_lin_vel_xy_exp` | exp(-error^2 / 0.25) | **+1.5** | Primary task reward (rough_a1 override from 1.0) |
| `track_ang_vel_z_exp` | exp(-error^2 / 0.25) | **+0.75** | Yaw tracking (rough_a1 override from 0.5) |
| `feet_air_time` | air time bonus for `.*_foot` | **+0.25** | Flat override (rough_a1 had 0.01, base had 0.125). Threshold = 0.5 s |
| `flat_orientation_l2` | L2 on projected gravity deviation | **-2.5** | Flat override (base had 0.0) -- penalizes tilt |
| `lin_vel_z_l2` | L2 on vertical velocity | **-2.0** | Inherited from base |
| `ang_vel_xy_l2` | L2 on roll/pitch angular vel | **-0.05** | Inherited from base |
| `dof_torques_l2` | L2 on joint torques | **-0.0002** | rough_a1 override (base had -1e-5) |
| `dof_acc_l2` | L2 on joint accelerations | **-2.5e-7** | Inherited from base (same in rough_a1) |
| `action_rate_l2` | L2 on action changes | **-0.01** | Inherited from base |
| `undesired_contacts` | -- | **disabled** | Set to `None` by rough_a1 (base penalized thigh contacts) |
| `dof_pos_limits` | -- | 0.0 | Inherited, effectively disabled |

## 6. Command Ranges

| Parameter | Value |
|---|---|
| `lin_vel_x` | [-1.0, 1.0] m/s |
| `lin_vel_y` | [-1.0, 1.0] m/s |
| `ang_vel_z` | [-1.0, 1.0] rad/s |
| `heading` | [-pi, pi] rad |
| Heading command | True (heading_control_stiffness = 0.5) |
| Resampling interval | 10.0 s |
| Rel standing envs | 2% |
| Rel heading envs | 100% |

## 7. Key Thresholds

| Threshold | Value | Context |
|---|---|---|
| Feet air time threshold | 0.5 s | Minimum air time to earn `feet_air_time` bonus |
| Illegal contact force | 1.0 N | Terminates if trunk contacts ground above this |
| Episode length | 20.0 s | Maximum episode duration |
| Soft joint limit factor | 0.9 | Joints limited to 90% of physical range |

## 8. Domain Randomization

### Startup events (applied once)
| Event | Parameter | A1 Value |
|---|---|---|
| Rigid body material | static/dynamic friction | 0.8 / 0.6 (64 buckets) |
| Add base mass | mass range on `trunk` | **[-1.0, +3.0] kg** (rough_a1 override; base was [-5, 5]) |
| Base COM shift | -- | **disabled** (`None` in rough_a1) |

### Reset events (each episode reset)
| Event | Parameter | A1 Value |
|---|---|---|
| External force/torque on `trunk` | force/torque | (0, 0) -- effectively zero |
| Reset base pose | x, y, yaw | [-0.5, 0.5] m, [-pi, pi] rad |
| Reset base velocity | all axes | **0.0** (rough_a1 override; base randomized to +/-0.5) |
| Reset joint positions | scale range | **(1.0, 1.0)** -- exact default pose (rough_a1 override; base was [0.5, 1.5]) |

### Interval events
| Event | Parameter | A1 Value |
|---|---|---|
| Push robot | -- | **disabled** (`None` in rough_a1) |

Note: For the **play** variant (`UnitreeA1FlatEnvCfg_PLAY`), observation corruption and external forces are also disabled.

## 9. Training Config

### skrl PPO (flat)
| Parameter | Value |
|---|---|
| Network | MLP [128, 128, 128] (shared architecture, ELU) |
| Separate policy/value | False |
| Rollout steps | 24 |
| Learning epochs | 5 |
| Mini batches | 4 |
| Discount (gamma) | 0.99 |
| GAE lambda | 0.95 |
| Learning rate | 1e-3 (KL-adaptive, threshold 0.01) |
| Clip ratio | 0.2 |
| Value clip | 0.2 |
| Entropy coeff | 0.01 |
| Grad norm clip | 1.0 |
| Total timesteps | 7200 (rollout steps, not env steps) |
| Seed | 42 |

### rsl_rl PPO (flat)
| Parameter | Value |
|---|---|
| Network | MLP [128, 128, 128] (actor + critic, ELU) |
| Max iterations | 300 |
| Steps per env | 24 |
| Init noise std | 1.0 |
| Obs normalization | False (actor and critic) |
| LR schedule | adaptive (desired_kl = 0.01) |
| Other PPO params | Same as skrl (gamma=0.99, lam=0.95, clip=0.2, entropy=0.01) |

### Scene
| Parameter | Value |
|---|---|
| Num envs (train) | 4096 |
| Env spacing | 2.5 m |
| Sim dt | 0.005 s |
| Decimation | 4 (policy at 50 Hz) |

## 10. Key File Paths

All paths relative to IsaacLab repo root:

```
source/isaaclab_tasks/.../locomotion/velocity/
  velocity_env_cfg.py                    # Base LocomotionVelocityRoughEnvCfg (rewards, obs, events)
  config/a1/
    rough_env_cfg.py                     # UnitreeA1RoughEnvCfg (A1-specific overrides)
    flat_env_cfg.py                      # UnitreeA1FlatEnvCfg (flat terrain overrides)
    __init__.py                          # Gym registration
    agents/
      skrl_flat_ppo_cfg.yaml             # skrl PPO hyperparams (flat)
      skrl_rough_ppo_cfg.yaml            # skrl PPO hyperparams (rough)
      rsl_rl_ppo_cfg.py                  # rsl_rl PPO configs (both flat + rough)
      sb3_ppo_cfg.yaml                   # Stable Baselines3 config

source/isaaclab_assets/.../robots/
  unitree.py                             # UNITREE_A1_CFG (actuators, init state, USD path)
```

## 11. Relevance to Harold

| Dimension | A1 | Harold | Ratio |
|---|----|---|---|
| Mass | ~12 kg | ~2 kg | 6x heavier |
| Leg length | ~0.25 m (thigh+calf) | ~0.15 m | 1.7x longer |
| DOF | 12 | 12 | Same topology |
| Actuator effort | 33.5 Nm | TBD | Much stronger |

**Scaling considerations:**

- **Action scale**: A1 uses 0.25. Harold may need a similar or smaller scale given shorter lever arms.
- **Velocity commands**: A1 commands up to 1.0 m/s. Harold's shorter legs mean max achievable velocity is lower; command ranges of ~0.3-0.5 m/s are more realistic.
- **Mass randomization**: A1 adds [-1, +3] kg to a 12 kg robot (up to +25%). Harold at 2 kg should use proportionally smaller ranges (e.g., [-0.2, +0.5] kg).
- **Reward weights**: The `dof_torques_l2` penalty (-0.0002) is tuned for A1's 33.5 Nm motors. Harold's weaker actuators produce smaller torques, so this penalty may need to be smaller or the weight rebalanced.
- **Feet air time threshold**: 0.5 s is tuned for A1's gait cycle. Harold's lighter body and shorter legs may have a faster natural gait frequency; a lower threshold (0.2-0.3 s) could be more appropriate.
- **Flat orientation penalty**: The -2.5 weight on `flat_orientation_l2` is significant and likely transferable, since keeping the body level is equally important for a small robot.
- **PD gains**: A1 uses Kp=25, Kd=0.5 with DCMotor model. These are absolute values and must be retuned for Harold's actuator characteristics.

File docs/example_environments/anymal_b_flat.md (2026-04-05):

# ANYmal B -- Flat Terrain Locomotion

Technical breakdown of the Isaac Lab flat-terrain velocity-tracking environment for the ANYmal B quadruped.

---

## 1. Overview

| Field | Value |
|---|---|
| Robot | ANYmal B (ANYbotics) |
| Gym ID | `Isaac-Velocity-Flat-Anymal-B-v0` |
| Terrain | Flat plane (no procedural generation) |
| Base config class | `AnymalBFlatEnvCfg` (inherits `AnymalBRoughEnvCfg` -> `LocomotionVelocityRoughEnvCfg`) |
| Num envs (default) | 4096 |
| Episode length | 20.0 s |
| Sim dt | 0.005 s |
| Decimation | 4 (control at 50 Hz) |

---

## 2. Robot Specs

| Parameter | Value |
|---|---|
| Mass | ~30 kg (base body) |
| DOF count | 12 (3 per leg: HAA, HFE, KFE) |
| Leg length | ~0.55 m (hip to foot) |
| Init height | 0.6 m |
| Actuator model | LSTM actuator net (`anydrive_3_lstm_jit.pt`) |
| Saturation effort | 120.0 Nm |
| Effort limit | 80.0 Nm |
| Velocity limit | 7.5 rad/s |
| Self-collisions | Enabled |
| Soft joint pos limit factor | 0.95 |

Default joint positions: HAA=0.0, front HFE=0.4, hind HFE=-0.4, front KFE=-0.8, hind KFE=0.8 rad.

---

## 3. Observation Space

**No height scan** -- removed for flat terrain. Total dimension: **48**.

| Term | Dim | Noise |
|---|-----|---|
| `base_lin_vel` | 3 | Uniform [-0.1, 0.1] |
| `base_ang_vel` | 3 | Uniform [-0.2, 0.2] |
| `projected_gravity` | 3 | Uniform [-0.05, 0.05] |
| `velocity_commands` | 3 | None |
| `joint_pos` (relative) | 12 | Uniform [-0.01, 0.01] |
| `joint_vel` (relative) | 12 | Uniform [-1.5, 1.5] |
| `last_action` | 12 | None |

Observation corruption enabled during training (`enable_corruption = True`), disabled during play.

---

## 4. Action Space

| Parameter | Value |
|---|---|
| Type | Joint position targets |
| Dimension | 12 |
| Scale | 0.5 |
| Offset | Default joint positions (use_default_offset=True) |
| Joint pattern | `.*` (all 12 joints) |

Actions are scaled by 0.5 and added to the default standing pose. The LSTM actuator net converts position targets to torques.

---

## 5. Reward Structure

All rewards are computed per-step. Positive = task incentives, negative = penalties.

| Reward Term | Function | Weight | Notes |
|---|---|---|---|
| `track_lin_vel_xy_exp` | `mdp.track_lin_vel_xy_exp` | **+1.0** | std=0.5; exp(-error^2/0.25) |
| `track_ang_vel_z_exp` | `mdp.track_ang_vel_z_exp` | **+0.5** | std=0.5; exp(-error^2/0.25) |
| `feet_air_time` | `mdp.feet_air_time` | **+0.5** | Threshold 0.5s; feet matching `.*FOOT` (**4x rough**) |
| `flat_orientation_l2` | `mdp.flat_orientation_l2` | **-5.0** | L2 of projected gravity error (**enabled for flat, 0.0 in rough**) |
| `lin_vel_z_l2` | `mdp.lin_vel_z_l2` | **-2.0** | Penalize vertical bounce |
| `ang_vel_xy_l2` | `mdp.ang_vel_xy_l2` | **-0.05** | Penalize roll/pitch rates |
| `dof_torques_l2` | `mdp.joint_torques_l2` | **-2.5e-5** | (**2.5x rough**) |
| `dof_acc_l2` | `mdp.joint_acc_l2` | **-2.5e-7** | Same as rough |
| `action_rate_l2` | `mdp.action_rate_l2` | **-0.01** | Smooth actions |
| `undesired_contacts` | `mdp.undesired_contacts` | **-1.0** | Thigh contacts > 1.0 N |
| `dof_pos_limits` | `mdp.joint_pos_limits` | 0.0 | Disabled |

**Key flat-vs-rough differences**: `flat_orientation_l2` activated at -5.0, `dof_torques_l2` raised to -2.5e-5, `feet_air_time` raised to +0.5.

---

## 6. Command Ranges

| Parameter | Value |
|---|---|
| lin_vel_x | [-1.0, 1.0] m/s |
| lin_vel_y | [-1.0, 1.0] m/s |
| ang_vel_z | [-1.0, 1.0] rad/s |
| heading | [-pi, pi] rad |
| Heading command | Enabled (stiffness=0.5) |
| Resampling interval | 10.0 s |
| Standing envs fraction | 2% (`rel_standing_envs=0.02`) |
| Heading envs fraction | 100% (`rel_heading_envs=1.0`) |

---

## 7. Key Thresholds

| Threshold | Value | Context |
|---|---|---|
| Feet air time target | 0.5 s | `feet_air_time` reward |
| Undesired contact force | 1.0 N | Thigh contact penalty |
| Illegal contact force | 1.0 N | Base contact -> termination |
| Max depenetration vel | 1.0 m/s | Physics solver |

---

## 8. Domain Randomization

**Startup (once per env):**

| Event | Range |
|---|---|
| Rigid body material | static_friction=0.8, dynamic_friction=0.6, restitution=0.0 (fixed, 64 buckets) |
| Base mass randomization | +/- 5.0 kg added to base |
| Base CoM offset | x: +/-0.05m, y: +/-0.05m, z: +/-0.01m |

**Reset (each episode):**

| Event | Range |
|---|---|
| Base pose | x: +/-0.5m, y: +/-0.5m, yaw: +/-pi |
| Base velocity | x/y/z: +/-0.5 m/s, roll/pitch/yaw: +/-0.5 rad/s |
| Joint positions | Scaled 0.5x--1.5x from default |
| External force/torque | Force: 0.0, Torque: 0.0 (effectively disabled) |

**Interval (during episode):**

| Event | Interval | Range |
|---|---|---|
| Push robot | 10--15 s | vx: +/-0.5 m/s, vy: +/-0.5 m/s |

**No terrain curriculum** for flat.

---

## 9. Training Config

### RSL-RL PPO

| Parameter | Value |
|---|---|
| Max iterations | 300 |
| Steps per env | 24 |
| Actor network | [128, 128, 128] ELU |
| Critic network | [128, 128, 128] ELU |
| Init noise std | 1.0 |
| Learning rate | 1e-3 (adaptive KL schedule) |
| Desired KL | 0.01 |
| Gamma | 0.99 |
| Lambda (GAE) | 0.95 |
| Clip param | 0.2 |
| Entropy coef | 0.005 |
| Value loss coef | 1.0 |
| Mini-batches | 4 |
| Learning epochs | 5 |
| Max grad norm | 1.0 |
| Obs normalization | Disabled (actor + critic) |

### skrl PPO

Same hyperparameters as RSL-RL. Network: [128, 128, 128] ELU. GaussianMixin policy with `initial_log_std=0.0`, clipped to [-20, 2]. Timesteps: 7200 (= 300 iterations x 24 steps). Seed: 42.

---

## 10. Key File Paths

Relative to IsaacLab root:

```
source/isaaclab_tasks/.../locomotion/velocity/
  velocity_env_cfg.py                          # Base LocomotionVelocityRoughEnvCfg
  config/anymal_b/
    __init__.py                                # Gym registration
    rough_env_cfg.py                           # AnymalBRoughEnvCfg (parent)
    flat_env_cfg.py                            # AnymalBFlatEnvCfg
    agents/
      rsl_rl_ppo_cfg.py                        # RSL-RL PPO configs
      skrl_flat_ppo_cfg.yaml                   # skrl flat PPO config
      skrl_rough_ppo_cfg.yaml                  # skrl rough PPO config

source/isaaclab_assets/.../robots/anymal.py    # ANYMAL_B_CFG, actuator configs

source/isaaclab/.../terrains/config/rough.py   # ROUGH_TERRAINS_CFG (not used for flat)
```

---

## 11. Relevance to Harold

| Dimension | ANYmal B | Harold | Ratio |
|---|---|---|---|
| Mass | ~30 kg | ~2 kg | 15:1 |
| Leg length | ~0.55 m | ~0.15 m | 3.7:1 |
| DOF | 12 (3/leg) | 12 (3/leg) | 1:1 |
| Actuator | 80 Nm ANYdrive (LSTM net) | Small servos | Orders of magnitude |
| Velocity cmd range | +/-1.0 m/s | Much lower (scaled to body) | ~3-5x |

**Scaling considerations for Harold:**

- **Mass randomization**: +/-5 kg is ~17% of ANYmal base mass. For Harold at ~2 kg, equivalent would be +/-0.3 kg.
- **Action scale**: 0.5 rad offset from default works for ANYmal's large joints; Harold may need different scaling given smaller servo range.
- **Velocity commands**: 1.0 m/s is moderate for ANYmal (~1.8 body-lengths/s). For Harold, 1.0 m/s would be ~6.7 body-lengths/s -- likely too fast. Harold experiments use lower thresholds (0.15 m/s range explored in EXP-775+).
- **Feet air time threshold**: 0.5 s assumes ANYmal's natural gait frequency. Harold's smaller legs cycle faster; threshold needs reduction.
- **Push velocity**: +/-0.5 m/s push is gentle for 30 kg ANYmal but would launch 2 kg Harold. Scale down proportionally.
- **Flat orientation penalty**: -5.0 weight is a strong signal for flat terrain. Harold's sim_flat_v2 baseline can adopt similar emphasis.
- **Network size**: [128, 128, 128] for flat is notably smaller than rough [512, 256, 128]. Harold's flat-terrain task may benefit from similar small networks.
- **Training duration**: Only 300 iterations for flat (vs 1500 rough). Flat terrain converges faster -- Harold autoresearch uses ~5000 iterations but on a harder problem (first-time walking).

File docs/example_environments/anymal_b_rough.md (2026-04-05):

# ANYmal B -- Rough Terrain Locomotion

Technical breakdown of the Isaac Lab rough-terrain velocity-tracking environment for the ANYmal B quadruped.

---

## 1. Overview

| Field | Value |
|---|---|
| Robot | ANYmal B (ANYbotics) |
| Gym ID | `Isaac-Velocity-Rough-Anymal-B-v0` |
| Terrain | Procedurally generated rough (6 sub-terrain types with curriculum) |
| Base config class | `AnymalBRoughEnvCfg` (inherits `LocomotionVelocityRoughEnvCfg`) |
| Num envs (default) | 4096 |
| Episode length | 20.0 s |
| Sim dt | 0.005 s |
| Decimation | 4 (control at 50 Hz) |

---

## 2. Robot Specs

| Parameter | Value |
|---|---|
| Mass | ~30 kg (base body) |
| DOF count | 12 (3 per leg: HAA, HFE, KFE) |
| Leg length | ~0.55 m (hip to foot) |
| Init height | 0.6 m |
| Actuator model | LSTM actuator net (`anydrive_3_lstm_jit.pt`) |
| Saturation effort | 120.0 Nm |
| Effort limit | 80.0 Nm |
| Velocity limit | 7.5 rad/s |
| Self-collisions | Enabled |
| Soft joint pos limit factor | 0.95 |

Default joint positions: HAA=0.0, front HFE=0.4, hind HFE=-0.4, front KFE=-0.8, hind KFE=0.8 rad.

---

## 3. Observation Space

**Includes height scan**. Total dimension: **235** (48 proprioceptive + 187 height scan).

| Term | Dim | Noise | Clip |
|---|-----|---|---|
| `base_lin_vel` | 3 | Uniform [-0.1, 0.1] | -- |
| `base_ang_vel` | 3 | Uniform [-0.2, 0.2] | -- |
| `projected_gravity` | 3 | Uniform [-0.05, 0.05] | -- |
| `velocity_commands` | 3 | None | -- |
| `joint_pos` (relative) | 12 | Uniform [-0.01, 0.01] | -- |
| `joint_vel` (relative) | 12 | Uniform [-1.5, 1.5] | -- |
| `last_action` | 12 | None | -- |
| `height_scan` | 187 | Uniform [-0.1, 0.1] | [-1.0, 1.0] |

Height scanner: RayCaster from base at +20m Z offset, yaw-aligned grid pattern, resolution=0.1m, size=[1.6m x 1.0m] = 17x11 = 187 rays.

Observation corruption enabled during training (`enable_corruption = True`), disabled during play.

---

## 4. Action Space

| Parameter | Value |
|---|---|
| Type | Joint position targets |
| Dimension | 12 |
| Scale | 0.5 |
| Offset | Default joint positions (use_default_offset=True) |
| Joint pattern | `.*` (all 12 joints) |

Actions are scaled by 0.5 and added to the default standing pose. The LSTM actuator net converts position targets to torques.

---

## 5. Reward Structure

All rewards are computed per-step. Positive = task incentives, negative = penalties.

| Reward Term | Function | Weight | Notes |
|---|---|---|---|
| `track_lin_vel_xy_exp` | `mdp.track_lin_vel_xy_exp` | **+1.0** | std=0.5; exp(-error^2/0.25) |
| `track_ang_vel_z_exp` | `mdp.track_ang_vel_z_exp` | **+0.5** | std=0.5; exp(-error^2/0.25) |
| `feet_air_time` | `mdp.feet_air_time` | **+0.125** | Threshold 0.5s; feet matching `.*FOOT` |
| `flat_orientation_l2` | `mdp.flat_orientation_l2` | **0.0** | Disabled for rough (terrain is uneven) |
| `lin_vel_z_l2` | `mdp.lin_vel_z_l2` | **-2.0** | Penalize vertical bounce |
| `ang_vel_xy_l2` | `mdp.ang_vel_xy_l2` | **-0.05** | Penalize roll/pitch rates |
| `dof_torques_l2` | `mdp.joint_torques_l2` | **-1.0e-5** | Energy penalty |
| `dof_acc_l2` | `mdp.joint_acc_l2` | **-2.5e-7** | Smooth joint accelerations |
| `action_rate_l2` | `mdp.action_rate_l2` | **-0.01** | Smooth actions |
| `undesired_contacts` | `mdp.undesired_contacts` | **-1.0** | Thigh contacts > 1.0 N |
| `dof_pos_limits` | `mdp.joint_pos_limits` | **0.0** | Disabled |

**Key rough-vs-flat differences**: `flat_orientation_l2` disabled (robot must tilt on slopes), lower `feet_air_time` weight (0.125 vs 0.5), lower `dof_torques_l2` penalty (1e-5 vs 2.5e-5).

---

## 6. Command Ranges

| Parameter | Value |
|---|---|
| lin_vel_x | [-1.0, 1.0] m/s |
| lin_vel_y | [-1.0, 1.0] m/s |
| ang_vel_z | [-1.0, 1.0] rad/s |
| heading | [-pi, pi] rad |
| Heading command | Enabled (stiffness=0.5) |
| Resampling interval | 10.0 s |
| Standing envs fraction | 2% (`rel_standing_envs=0.02`) |
| Heading envs fraction | 100% (`rel_heading_envs=1.0`) |

---

## 7. Key Thresholds

| Threshold | Value | Context |
|---|---|---|
| Feet air time target | 0.5 s | `feet_air_time` reward |
| Undesired contact force | 1.0 N | Thigh contact penalty |
| Illegal contact force | 1.0 N | Base contact -> termination |
| Max init terrain level | 5 | Curriculum starting difficulty |
| Height scan clip | [-1.0, 1.0] m | Observation clipping |
| Max depenetration vel | 1.0 m/s | Physics solver |

---

## 8. Domain Randomization

**Startup (once per env):**

| Event | Range |
|---|---|
| Rigid body material | static_friction=0.8, dynamic_friction=0.6, restitution=0.0 (fixed, 64 buckets) |
| Base mass randomization | +/- 5.0 kg added to base |
| Base CoM offset | x: +/-0.05m, y: +/-0.05m, z: +/-0.01m |

**Reset (each episode):**

| Event | Range |
|---|---|
| Base pose | x: +/-0.5m, y: +/-0.5m, yaw: +/-pi |
| Base velocity | x/y/z: +/-0.5 m/s, roll/pitch/yaw: +/-0.5 rad/s |
| Joint positions | Scaled 0.5x--1.5x from default |
| External force/torque | Force: 0.0, Torque: 0.0 (effectively disabled) |

**Interval (during episode):**

| Event | Interval | Range |
|---|---|---|
| Push robot | 10--15 s | vx: +/-0.5 m/s, vy: +/-0.5 m/s |

**Terrain curriculum** enabled: terrains generated with increasing difficulty. 10 rows x 20 cols grid, each tile 8m x 8m.

---

## 9. Terrain Configuration (ROUGH_TERRAINS_CFG)

Grid: 10 rows x 20 cols, tile size 8.0m x 8.0m, border 20.0m, horizontal_scale=0.1m, vertical_scale=0.005m.

| Sub-terrain | Proportion | Key Parameters |
|---|---|---|
| `pyramid_stairs` | 20% | step_height 0.05--0.23m, step_width 0.3m, platform 3.0m |
| `pyramid_stairs_inv` (inverted) | 20% | step_height 0.05--0.23m, step_width 0.3m, platform 3.0m |
| `boxes` (random grid) | 20% | grid_width 0.45m, grid_height 0.05--0.2m, platform 2.0m |
| `random_rough` | 20% | noise 0.02--0.10m, noise_step 0.02m |
| `hf_pyramid_slope` | 10% | slope 0.0--0.4, platform 2.0m |
| `hf_pyramid_slope_inv` | 10% | slope 0.0--0.4, platform 2.0m |

---

## 10. Training Config

### RSL-RL PPO

| Parameter | Value |
|---|---|
| Max iterations | 1500 |
| Steps per env | 24 |
| Actor network | [512, 256, 128] ELU |
| Critic network | [512, 256, 128] ELU |
| Init noise std | 1.0 |
| Learning rate | 1e-3 (adaptive KL schedule) |
| Desired KL | 0.01 |
| Gamma | 0.99 |
| Lambda (GAE) | 0.95 |
| Clip param | 0.2 |
| Entropy coef | 0.005 |
| Value loss coef | 1.0 |
| Mini-batches | 4 |
| Learning epochs | 5 |
| Max grad norm | 1.0 |
| Obs normalization | Disabled (actor + critic) |

### skrl PPO

Same hyperparameters as RSL-RL. Network: [512, 256, 128] ELU. GaussianMixin policy with `initial_log_std=0.0`, clipped to [-20, 2]. Timesteps: 36000 (= 1500 iterations x 24 steps). Seed: 42.

**Rough uses a 5x larger network and 5x more training iterations than flat.**

---

## 11. Key File Paths

Relative to IsaacLab root:

```
source/isaaclab_tasks/.../locomotion/velocity/
  velocity_env_cfg.py                          # Base LocomotionVelocityRoughEnvCfg
  config/anymal_b/
    __init__.py                                # Gym registration
    rough_env_cfg.py                           # AnymalBRoughEnvCfg
    flat_env_cfg.py                            # AnymalBFlatEnvCfg (inherits rough)
    agents/
      rsl_rl_ppo_cfg.py                        # RSL-RL PPO configs
      skrl_flat_ppo_cfg.yaml                   # skrl flat PPO config
      skrl_rough_ppo_cfg.yaml                  # skrl rough PPO config

source/isaaclab_assets/.../robots/anymal.py    # ANYMAL_B_CFG, actuator configs

source/isaaclab/.../terrains/config/rough.py   # ROUGH_TERRAINS_CFG
```

---

## 12. Relevance to Harold

| Dimension | ANYmal B | Harold | Ratio |
|---|---|---|---|
| Mass | ~30 kg | ~2 kg | 15:1 |
| Leg length | ~0.55 m | ~0.15 m | 3.7:1 |
| DOF | 12 (3/leg) | 12 (3/leg) | 1:1 |
| Actuator | 80 Nm ANYdrive (LSTM net) | Small servos | Orders of magnitude |
| Velocity cmd range | +/-1.0 m/s | Much lower (scaled to body) | ~3-5x |

**Scaling considerations for Harold:**

- **Height scan**: 187-dim exteroceptive observation is only needed for rough terrain. Harold's current work is flat-terrain-first, so this is not immediately relevant. When Harold moves to rough, the scan grid dimensions (1.6m x 1.0m) would need scaling to Harold's footprint (~0.3m x 0.2m).
- **Network size**: [512, 256, 128] for rough is large. Harold's flat task uses smaller networks; rough terrain would likely need capacity increase but probably not to ANYmal's level given Harold's simpler dynamics.
- **Terrain curriculum**: ANYmal starts at level 5 of 10 difficulty rows. For Harold, terrain difficulty ranges (step heights 0.05--0.23m) are larger than Harold's entire leg length (0.15m). Terrain generation would need complete reparameterization.
- **Mass randomization**: +/-5 kg is ~17% of ANYmal. For Harold, equivalent would be +/-0.3 kg.
- **Velocity commands**: 1.0 m/s is moderate for ANYmal (~1.8 body-lengths/s). For Harold, 1.0 m/s would be ~6.7 body-lengths/s. Harold experiments use 0.15 m/s velocity thresholds (EXP-775+).
- **Feet air time**: 0.5 s threshold assumes ANYmal's natural stride frequency (~2 Hz). Harold's smaller legs cycle faster; threshold needs scaling down.
- **Push disturbance**: +/-0.5 m/s every 10--15 s is gentle for 30 kg. For 2 kg Harold this is a massive perturbation. Scale impulse by mass ratio.
- **Training duration**: 1500 iterations for rough terrain. Harold at 5000 iterations is already 3x longer but solving a different (arguably harder) problem -- learning to walk at all rather than refining an established gait on varied terrain.
- **Orientation penalty**: Disabled (0.0) for rough because the robot must tilt on slopes. This is a useful design pattern: separate flat and rough reward tuning.

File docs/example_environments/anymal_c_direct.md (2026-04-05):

# ANYmal C Direct Environment -- Technical Breakdown

Reference implementation of a **direct** (non-manager-based) quadruped locomotion environment in Isaac Lab.
This is the same architecture Harold uses.

---

## 1. Overview

| Field | Value |
|---|---|
| Robot | ANYmal C (ANYbotics) |
| Gym IDs | `Isaac-Velocity-Flat-Anymal-C-Direct-v0`, `Isaac-Velocity-Rough-Anymal-C-Direct-v0` |
| Terrain | Flat plane (flat variant) / procedural rough (rough variant) |
| Architecture | **DirectRLEnv** -- all observations, rewards, resets, and actions are computed in a single Python class with explicit tensor math. No manager infrastructure. |
| Base class | `isaaclab.envs.DirectRLEnv` |
| Episode length | 20 s |
| Sim dt | 1/200 s (0.005 s) |
| Decimation | 4 (policy runs at 50 Hz) |
| Num envs (default) | 4096, spacing 4.0 m |

---

## 2. Robot Specs

| Field | Value |
|---|---|
| Mass | ~50 kg (ANYmal C nominal) |
| DOF | 12 (3 per leg: HAA, HFE, KFE) |
| Init height | 0.6 m |
| Actuator model | `ActuatorNetLSTMCfg` (learned LSTM actuator net for ANYdrive 3.0) |
| Effort limit | 80 N*m (saturation 120 N*m) |
| Velocity limit | 7.5 rad/s |
| Joint stiffness / damping | N/A (LSTM net replaces PD) |
| Default joint pos | HAA=0.0, front HFE=0.4, hind HFE=-0.4, front KFE=-0.8, hind KFE=0.8 |
| Self-collisions | Enabled |
| Soft joint pos limit factor | 0.95 |

---

## 3. Observation Space

**Flat variant: 48 dims. Rough variant: 235 dims** (48 + 187 height scan).

Observations are concatenated in this exact order (see `_get_observations`):

| # | Observation | Dims | Notes |
|---|---|---|---|
| 1 | `root_lin_vel_b` | 3 | Base linear velocity in body frame |
| 2 | `root_ang_vel_b` | 3 | Base angular velocity in body frame |
| 3 | `projected_gravity_b` | 3 | Gravity vector projected into body frame |
| 4 | `commands` | 3 | (vx, vy, wz) velocity commands |
| 5 | `joint_pos - default_joint_pos` | 12 | Joint position deviation from default |
| 6 | `joint_vel` | 12 | Joint velocities |
| 7 | `height_data` | 187 | **Rough only.** Height scan from RayCaster, clipped to [-1, 1] |
| 8 | `actions` | 12 | Previous actions (set from `_actions` at the start of `_get_observations`) |

**No observation noise** is applied in the direct variant. The manager-based variant adds uniform noise to most observations; the direct env does not.

---

## 4. Action Space

| Field | Value |
|---|---|
| Dims | 12 (one per joint) |
| Control mode | Joint position targets |
| Scaling | `action_scale = 0.5` |
| Processing | `processed_actions = 0.5 * actions + default_joint_pos` |
| Application | `set_joint_position_target(processed_actions)` |

Actions are **offsets from the default joint configuration**, scaled by 0.5 radians. The LSTM actuator net then converts position targets into joint torques internally.

---

## 5. Reward Structure

All 10 reward terms, with exact computation from the code. Every term is multiplied by `self.step_dt` (= decimation * sim_dt = 0.02 s at 50 Hz policy).

### 5.1 Tracking Rewards (positive)

| Term | Weight (flat) | Computation |
|---|---|---|
| **track_lin_vel_xy_exp** | **+1.0** | `exp(-sum((cmd_xy - vel_xy)^2) / 0.25)` -- Gaussian kernel on XY velocity error, sigma^2 = 0.25 |
| **track_ang_vel_z_exp** | **+0.5** | `exp(-(cmd_wz - wz)^2 / 0.25)` -- Gaussian kernel on yaw rate error, sigma^2 = 0.25 |
| **feet_air_time** | **+0.5** | `sum((last_air_time - 0.5) * first_contact)` gated by `norm(cmd_xy) > 0.1`. Rewards feet that stay in the air for ~0.5 s before touching down. Only active when the robot is commanded to move. |

### 5.2 Penalties (negative)

| Term | Weight (flat) | Computation |
|---|---|---|
| **lin_vel_z_l2** | **-2.0** | `vel_z^2` -- Penalizes vertical bouncing |
| **ang_vel_xy_l2** | **-0.05** | `sum(ang_vel_xy^2)` -- Penalizes roll/pitch angular velocity |
| **dof_torques_l2** | **-2.5e-5** | `sum(applied_torque^2)` -- Penalizes high joint torques |
| **dof_acc_l2** | **-2.5e-7** | `sum(joint_acc^2)` -- Penalizes joint acceleration |
| **action_rate_l2** | **-0.01** | `sum((action_t - action_{t-1})^2)` -- Penalizes jerky actions |
| **undesired_contacts** | **-1.0** | Count of `*THIGH` bodies with contact force > 1.0 N (from 3-step history). Penalizes thigh-ground contact. |
| **flat_orientation_l2** | **-5.0** (flat) / **0.0** (rough) | `sum(projected_gravity_xy^2)` -- Penalizes body tilt. Disabled on rough terrain. |

### 5.3 Reward Aggregation

```python
reward = sum(all_reward_terms)  # simple summation, no clipping
```

Each term is: `raw_value * weight * step_dt`. The `step_dt` factor normalizes rewards to be per-second rather than per-step.

### 5.4 Reward Scale Comparison: Direct vs Manager-Based

The direct and manager-based ANYmal C envs use **almost** the same reward scales, but there are two notable differences:

| Term | Direct (flat) | Manager-based (rough) |
|---|---|---|
| dof_torques_l2 | -2.5e-5 | -1.0e-5 |
| feet_air_time | +0.5 | +0.125 |
| flat_orientation_l2 | -5.0 | 0.0 (disabled) |

The manager-based version also has `dof_pos_limits` (weight 0.0, disabled) which is absent from the direct version.

---

## 6. Command Ranges

Commands are sampled **uniformly** in `_reset_idx`:

```python
self._commands[env_ids] = torch.zeros_like(self._commands[env_ids]).uniform_(-1.0, 1.0)
```

| Command | Range | Units |
|---|---|---|
| vx (forward) | [-1.0, 1.0] | m/s |
| vy (lateral) | [-1.0, 1.0] | m/s |
| wz (yaw rate) | [-1.0, 1.0] | rad/s |

Commands are sampled once per episode reset and **never resampled** mid-episode. The manager-based variant resamples every 10 s and includes heading commands; the direct variant does not.

---

## 7. Key Thresholds

| Parameter | Value | Where Used |
|---|---|---|
| Feet air time target | 0.5 s | `(last_air_time - 0.5) * first_contact` in feet_air_time reward |
| Velocity gate for gait reward | 0.1 m/s | `norm(cmd_xy) > 0.1` -- gait reward is zero when standing |
| Undesired contact force threshold | 1.0 N | Thigh contacts above this count as undesired |
| Base contact termination threshold | 1.0 N | Any base contact force > 1 N triggers episode death |
| Contact sensor history length | 3 steps | Used for undesired contact and termination checks |
| Contact sensor update period | 0.005 s | Matches sim dt |

---

## 8. Domain Randomization

The direct ANYmal C env has **minimal** randomization -- only two terms at startup, no runtime perturbations:

| Event | Mode | Details |
|---|---|---|
| **physics_material** | startup | Friction: static=0.8, dynamic=0.6, restitution=0.0 (deterministic, not random ranges). 64 buckets. |
| **add_base_mass** | startup | Base mass +/- 5.0 kg (uniform). |

**Not present** (but present in manager-based):
- No base COM randomization
- No external force/torque perturbations
- No periodic push events
- No initial pose/velocity randomization (reset goes to exact default state + terrain offset)
- No joint position randomization on reset
- No observation noise

This is a significant difference from the manager-based version which has 6 randomization events.

---

## 9. Training Config (skrl PPO)

### Flat Variant

| Parameter | Value |
|---|---|
| Seed | 42 |
| Network | [128, 128, 128] MLP, ELU, shared backbone (separate=False) |
| Policy class | GaussianMixin (continuous) |
| initial_log_std | 0.0 |
| Rollout length | 24 steps |
| Learning epochs | 5 |
| Mini-batches | 4 |
| Discount (gamma) | 0.99 |
| GAE lambda | 0.95 |
| Learning rate | 1e-3, KL-adaptive (threshold 0.01) |
| Clip ratio | 0.2 (both policy and value) |
| Entropy coeff | 0.005 |
| Value loss coeff | 1.0 |
| Grad norm clip | 1.0 |
| Reward shaper scale | 0.6 |
| Timesteps | 36,000 (= 36000/24 = 1500 updates at 4096 envs) |
| Value preprocessor | RunningStandardScaler |

### Rough Variant

Identical to flat except:
- Network: [512, 256, 128] (larger for height scan input)
- All other hyperparameters are the same

---

## 10. Key File Paths

All paths relative to IsaacLab repo root:

```
source/isaaclab_tasks/isaaclab_tasks/direct/anymal_c/
    __init__.py              # Gym registration
    anymal_c_env.py          # Environment class (AnymalCEnv)
    anymal_c_env_cfg.py      # Config classes (AnymalCFlatEnvCfg, AnymalCRoughEnvCfg)
    agents/
        skrl_flat_ppo_cfg.yaml
        skrl_rough_ppo_cfg.yaml
        rsl_rl_ppo_cfg.py
        rl_games_flat_ppo_cfg.yaml
        rl_games_rough_ppo_cfg.yaml

source/isaaclab_assets/isaaclab_assets/robots/anymal.py   # Robot ArticulationCfg

# Manager-based counterpart (for comparison):
source/isaaclab_tasks/isaaclab_tasks/manager_based/locomotion/velocity/
    velocity_env_cfg.py      # Base config with all reward/obs/event managers
    config/anymal_c/
        rough_env_cfg.py     # ANYmal C manager-based rough config
```

---

## 11. Direct vs Manager-Based Architecture

This is the most important section for Harold development. The ANYmal C environment exists in **both** architectures in the Isaac Lab codebase, making it the canonical comparison.

### How Direct Implements Rewards

In the direct env, rewards are computed in a single `_get_rewards()` method as raw tensor operations:

```python
def _get_rewards(self) -> torch.Tensor:
    lin_vel_error = torch.sum(torch.square(self._commands[:, :2] - self._robot.data.root_lin_vel_b[:, :2]), dim=1)
    lin_vel_error_mapped = torch.exp(-lin_vel_error / 0.25)
    ...
    rewards = {
        "track_lin_vel_xy_exp": lin_vel_error_mapped * self.cfg.lin_vel_reward_scale * self.step_dt,
        ...
    }
    reward = torch.sum(torch.stack(list(rewards.values())), dim=0)
    return reward
```

Key properties:
- **Weights are multiplied inline** with `self.cfg.<name>_reward_scale * self.step_dt`
- **No manager dispatch** -- no `RewTerm` wrappers, no `func` references, no `params` dict
- **No automatic `step_dt` multiplication** -- the direct env must do it manually (the manager-based `RewardManager` does it automatically)
- **Reward functions are not reusable** -- they are hardcoded in the env class, not in a shared `mdp` module

### How Manager-Based Implements Rewards

In the manager-based env, rewards are declared as config objects:

```python
track_lin_vel_xy_exp = RewTerm(
    func=mdp.track_lin_vel_xy_exp, weight=1.0,
    params={"command_name": "base_velocity", "std": math.sqrt(0.25)}
)
```

Key properties:
- **Weights are declared in config**, applied by `RewardManager`
- **`step_dt` multiplication is automatic** -- the `RewardManager` multiplies every term by `dt`
- **Functions live in `mdp` module** -- reusable across envs
- **Noise, corruption, and clipping** are handled by `ObservationManager`

### Critical Differences for Porting

| Aspect | Manager-Based | Direct |
|---|---|---|
| `step_dt` multiplication | Automatic (by RewardManager) | **Manual** -- must multiply every reward term by `self.step_dt` |
| Observation noise | Configured via `Unoise` on each `ObsTerm` | Must be added manually (ANYmal C direct does NOT add any) |
| Command resampling | Automatic by `CommandManager` (every 10 s) | Manual in `_reset_idx` only (once per episode) |
| Standing envs | `rel_standing_envs=0.02` (2% get zero commands) | Not implemented |
| Heading command | Supported via `heading_command=True` | Not implemented (only vx, vy, wz) |
| Reset randomization | 5 events (pose, velocity, joints, push, external force) | 0 runtime events (only default state + terrain offset) |
| Reward function signature | `func(env, ...) -> Tensor` | Inline tensor math in `_get_rewards()` |
| Adding/removing rewards | Change config dict | Edit Python code |

### The `step_dt` Trap

The most dangerous porting bug: in manager-based configs, reward weights are "per second" because `RewardManager` multiplies by `dt`. When porting to direct, you must **manually** multiply each reward term by `self.step_dt`. If you forget, rewards will be 50x larger than intended (at 50 Hz policy rate). If you multiply twice, they will be 50x smaller.

The ANYmal C direct env does this correctly:
```python
"track_lin_vel_xy_exp": lin_vel_error_mapped * self.cfg.lin_vel_reward_scale * self.step_dt,
```

---

## 12. Relevance to Harold

Harold's `sim_flat_v2` was ported from the **manager-based Spot config** to a **direct architecture**. The ANYmal C direct env is the official reference for how to do this correctly.

### What Harold Should Verify Against This Reference

1. **`step_dt` multiplication**: Every reward term in Harold's `_get_rewards()` must include `* self.step_dt`. Cross-check against ANYmal C's pattern.

2. **Reward computation correctness**: The tracking rewards use `exp(-error / sigma^2)` with sigma^2=0.25. Verify Harold uses the same kernel and does not accidentally use a different sigma or forget the negative sign.

3. **Feet air time gating**: ANYmal C gates the gait reward with `norm(cmd_xy) > 0.1` so standing robots are not rewarded for lifting feet. Harold's velocity threshold experiments (EXP-775+) are exploring this same concept.

4. **Undesired contacts**: ANYmal C checks `*THIGH` bodies using contact force history (max over 3 timesteps > 1.0 N). Verify Harold's contact body selection and threshold match the intended anatomy.

5. **Termination**: ANYmal C terminates only on base contact (> 1 N) and timeout. No other termination conditions. This is simpler than many locomotion envs.

6. **Missing randomization**: The direct ANYmal C env has almost no domain randomization compared to its manager-based counterpart. If Harold's direct port also dropped randomization events during porting, this could explain training instability or sim-to-real gaps.

7. **Command resampling**: ANYmal C direct samples commands once per episode. The manager-based version resamples every 10 s. If Harold needs command resampling, it must be implemented manually.

8. **Observation noise**: The direct env has none. If Harold needs noise for sim-to-real transfer, it must add it explicitly in `_get_observations()`.

### Architectural Lesson

The direct architecture trades configurability for transparency. Every computation is visible in one file, there is no hidden `step_dt` multiplication, no manager dispatch overhead, and no risk of config inheritance bugs. The cost is that changes require editing Python code rather than swapping config values. For an experimental project like Harold, this transparency is a net positive -- reward bugs are immediately visible in the source.

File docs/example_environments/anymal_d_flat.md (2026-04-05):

# ANYmal D Flat Locomotion Environment

Technical breakdown of the Isaac Lab ANYmal D flat-terrain velocity-tracking environment.

Source: local IsaacLab checkout + [GitHub main branch](https://github.com/isaac-sim/IsaacLab/tree/main/source/isaaclab_tasks/isaaclab_tasks/manager_based/locomotion/velocity/config/anymal_d).

---

## 1. Overview

| Field | Value |
|---|---|
| Robot | ANYmal D (ANYbotics) |
| Gym ID | `Isaac-Velocity-Flat-Anymal-D-v0` |
| Play Gym ID | `Isaac-Velocity-Flat-Anymal-D-Play-v0` |
| Terrain | Flat plane (no generator, no curriculum) |
| Base class chain | `AnymalDFlatEnvCfg` -> `AnymalDRoughEnvCfg` -> `LocomotionVelocityRoughEnvCfg` -> `ManagerBasedRLEnvCfg` |

The flat env inherits from the rough env and overrides: terrain to flat plane, removes height scanner, adjusts three reward weights, and disables terrain curriculum.

---

## 2. Robot Specs

| Parameter | Value |
|---|---|
| Mass | ~50 kg (nominal) |
| DOF | 12 (4 legs x 3 joints: HAA, HFE, KFE) |
| Leg length | ~0.55 m (upper + lower) |
| Init height | 0.6 m |
| Actuator model | LSTM actuator net (ANYdrive 3.0, re-used from ANYmal C) |
| Saturation effort | 120.0 Nm |
| Effort limit | 80.0 Nm |
| Velocity limit | 7.5 rad/s |
| PD gains | Kp=40.0, Kd=5.0 (DC motor fallback) |
| Self-collisions | Enabled |
| Solver iters | Position: 4, Velocity: 0 |
| Soft joint pos limit factor | 0.95 |

Default joint positions:

| Joint group | Init pos (rad) |
|---|---|
| `.*HAA` | 0.0 |
| `.*F_HFE` (front hip) | 0.4 |
| `.*H_HFE` (hind hip) | -0.4 |
| `.*F_KFE` (front knee) | -0.8 |
| `.*H_KFE` (hind knee) | 0.8 |

---

## 3. Observation Space

**Total dimension: 48** (no height scan on flat).

| Observation | Dim | Noise | Notes |
|---|---|---|---|
| `base_lin_vel` | 3 | U(-0.1, 0.1) | Base linear velocity in body frame |
| `base_ang_vel` | 3 | U(-0.2, 0.2) | Base angular velocity in body frame |
| `projected_gravity` | 3 | U(-0.05, 0.05) | Gravity vector in body frame |
| `velocity_commands` | 3 | None | Commanded (vx, vy, wz) |
| `joint_pos` | 12 | U(-0.01, 0.01) | Relative joint positions |
| `joint_vel` | 12 | U(-1.5, 1.5) | Relative joint velocities |
| `actions` | 12 | None | Previous actions |
| ~~`height_scan`~~ | ~~187~~ | -- | **Removed** for flat env |

- `enable_corruption = True` (additive uniform noise during training)
- `concatenate_terms = True`

---

## 4. Action Space

| Parameter | Value |
|---|---|
| Action type | Joint position targets |
| Dimension | 12 |
| Scale | 0.5 |
| Offset | Default joint positions (`use_default_offset=True`) |
| Joint names | `[".*"]` (all 12 joints) |

Actions are position offsets scaled by 0.5 and added to default standing pose.

---

## 5. Reward Structure

All rewards inherited from `LocomotionVelocityRoughEnvCfg`, with three weights overridden for flat terrain.

| Reward term | Weight | Function | Notes |
|---|---|---|---|
| `track_lin_vel_xy_exp` | **+1.0** | exp(-error^2/0.25) | Primary task: track xy velocity |
| `track_ang_vel_z_exp` | **+0.5** | exp(-error^2/0.25) | Track yaw rate |
| `feet_air_time` | **+0.5** | air time bonus | **Flat override** (rough: 0.125). Threshold=0.5s, feet=`.*FOOT` |
| `lin_vel_z_l2` | **-2.0** | L2 vertical velocity | Penalize bouncing |
| `ang_vel_xy_l2` | **-0.05** | L2 roll/pitch rate | Penalize body rotation |
| `dof_torques_l2` | **-2.5e-5** | L2 joint torques | **Flat override** (rough: -1.0e-5). Higher penalty |
| `dof_acc_l2` | **-2.5e-7** | L2 joint accelerations | Smooth motion |
| `action_rate_l2` | **-0.01** | L2 action rate | Smooth actions |
| `undesired_contacts` | **-1.0** | thigh contacts > 1.0N | Bodies: `.*THIGH` |
| `flat_orientation_l2` | **-5.0** | L2 orientation error | **Flat override** (rough: 0.0). Strong penalty for tilting |
| `dof_pos_limits` | 0.0 | joint limit violation | Disabled |

Key flat-terrain changes vs rough: `flat_orientation_l2` goes from 0.0 to -5.0 (enforces level body), `dof_torques_l2` goes from -1.0e-5 to -2.5e-5 (more torque penalty), `feet_air_time` goes from 0.125 to 0.5 (stronger gait reward).

---

## 6. Command Ranges

| Parameter | Value |
|---|---|
| `lin_vel_x` | [-1.0, 1.0] m/s |
| `lin_vel_y` | [-1.0, 1.0] m/s |
| `ang_vel_z` | [-1.0, 1.0] rad/s |
| `heading` | [-pi, pi] rad |
| Resampling interval | 10.0 s (fixed) |
| Standing envs fraction | 0.02 (2%) |
| Heading envs fraction | 1.0 (100%) |
| Heading command | True |
| Heading control stiffness | 0.5 |

---

## 7. Key Thresholds

| Parameter | Value |
|---|---|
| Sim dt | 0.005 s (200 Hz physics) |
| Decimation | 4 (policy at 50 Hz) |
| Episode length | 20.0 s |
| Feet air time threshold | 0.5 s |
| Undesired contact threshold | 1.0 N |
| Illegal contact threshold (termination) | 1.0 N on base |
| Terrain friction (static) | 1.0 |
| Terrain friction (dynamic) | 1.0 |
| Num envs (training) | 4096 |
| Env spacing | 2.5 m |

---

## 8. Domain Randomization

### Startup (once per env)

| Event | Parameters |
|---|---|
| Physics material | static_friction=0.8, dynamic_friction=0.6, restitution=0.0 (64 buckets, **not** randomized -- range is degenerate) |
| Base mass | Add U(-5.0, +5.0) kg to base body |
| Base COM offset | x: U(-0.05, 0.05), y: U(-0.05, 0.05), z: U(-0.01, 0.01) m |

### Reset (every episode reset)

| Event | Parameters |
|---|---|
| External force/torque | force=(0,0), torque=(0,0) -- effectively disabled |
| Root state | pos: U(-0.5,0.5) xy, yaw: U(-pi,pi); vel: U(-0.5,0.5) all axes |
| Joint reset | position scale U(0.5, 1.5) of default, velocity=0 |

### Interval (during episode)

| Event | Parameters |
|---|---|
| Push robot | Every 10-15s, set velocity x,y: U(-0.5, 0.5) m/s |

---

## 9. Training Config

### RSL-RL PPO (Flat)

| Parameter | Value |
|---|---|
| Network (actor) | [128, 128, 128] MLP, ELU |
| Network (critic) | [128, 128, 128] MLP, ELU |
| Init noise std | 1.0 |
| Obs normalization | False (actor + critic) |
| Num steps per env | 24 |
| Max iterations | 300 |
| Learning rate | 1.0e-3 (adaptive KL schedule) |
| Desired KL | 0.01 |
| Clip param | 0.2 |
| Entropy coef | 0.005 |
| Value loss coef | 1.0 |
| Gamma | 0.99 |
| Lambda (GAE) | 0.95 |
| Mini batches | 4 |
| Learning epochs | 5 |
| Max grad norm | 1.0 |
| Save interval | 50 |

### skrl PPO (Flat)

| Parameter | Value |
|---|---|
| Network | [128, 128, 128] MLP, ELU (shared structure) |
| Rollouts | 24 |
| Timesteps | 7200 (= 300 iterations x 24 rollout steps) |
| Learning rate | 1.0e-3 (KLAdaptiveLR, threshold=0.01) |
| Other PPO params | Same as RSL-RL above |
| Seed | 42 |

---

## 10. Key File Paths

Relative to IsaacLab repo root:

| File | Purpose |
|---|---|
| `source/isaaclab_tasks/.../locomotion/velocity/config/anymal_d/flat_env_cfg.py` | Flat env config |
| `source/isaaclab_tasks/.../locomotion/velocity/config/anymal_d/rough_env_cfg.py` | Rough base config (parent) |
| `source/isaaclab_tasks/.../locomotion/velocity/velocity_env_cfg.py` | Base env config (rewards, obs, events) |
| `source/isaaclab_tasks/.../locomotion/velocity/config/anymal_d/__init__.py` | Gym registration |
| `source/isaaclab_tasks/.../locomotion/velocity/config/anymal_d/agents/rsl_rl_ppo_cfg.py` | RSL-RL PPO config |
| `source/isaaclab_tasks/.../locomotion/velocity/config/anymal_d/agents/skrl_flat_ppo_cfg.yaml` | skrl PPO config |
| `source/isaaclab_assets/isaaclab_assets/robots/anymal.py` | Robot articulation config |
| `source/isaaclab/isaaclab/terrains/config/rough.py` | Rough terrain generator config |

---

## 11. Relevance to Harold

ANYmal D and Harold are fundamentally different-scale robots. Direct parameter transfer will not work.

| Dimension | ANYmal D | Harold | Ratio |
|---|---|---|---|
| Mass | ~50 kg | ~2 kg | 25x |
| Leg length | ~0.55 m | ~0.15 m | 3.7x |
| Actuator torque limit | 80 Nm | ~0.5 Nm | 160x |
| Standing height | 0.6 m | ~0.12 m | 5x |
| Velocity command range | +/-1.0 m/s | TBD (scaled) | -- |

### What transfers well
- **Reward structure**: The reward terms and their relative signs are a good starting point. The exponential velocity tracking with std=sqrt(0.25) is well-tested.
- **Observation set**: The 48-dim flat obs (no height scan) is a clean baseline for Harold.
- **PPO hyperparameters**: lr=1e-3, gamma=0.99, lam=0.95, clip=0.2, entropy=0.005 are reasonable defaults.
- **Episode structure**: 20s episodes, 50 Hz policy, 200 Hz physics.

### What needs scaling for Harold
- **Action scale**: 0.5 rad offset is large for Harold's small servos. Harold likely needs smaller scale.
- **Reward weights**: Torque penalty (-2.5e-5) is tuned for 80 Nm actuators; Harold's ~0.5 Nm actuators need a much larger penalty coefficient to have equivalent effect.
- **Mass randomization**: +/-5 kg is 10% of ANYmal but would be 250% of Harold. Scale to +/-0.1 kg or similar.
- **COM randomization**: +/-5 cm is small for ANYmal but large relative to Harold's body. Scale down proportionally.
- **Push velocity**: +/-0.5 m/s push is gentle for 50 kg but violent for 2 kg. Scale down significantly.
- **Velocity commands**: +/-1.0 m/s may be reasonable for Harold in body-lengths/s terms, but the gait rewards (feet_air_time threshold=0.5s) need tuning for Harold's faster gait frequency.
- **Feet air time threshold**: 0.5s assumes ANYmal's slow gait. Harold's legs are much shorter and will cycle faster; threshold should be ~0.1-0.2s.

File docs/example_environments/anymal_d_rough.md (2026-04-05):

# ANYmal D Rough Locomotion Environment

Technical breakdown of the Isaac Lab ANYmal D rough-terrain velocity-tracking environment.

Source: local IsaacLab checkout + [GitHub main branch](https://github.com/isaac-sim/IsaacLab/tree/main/source/isaaclab_tasks/isaaclab_tasks/manager_based/locomotion/velocity/config/anymal_d).

---

## 1. Overview

| Field | Value |
|---|---|
| Robot | ANYmal D (ANYbotics) |
| Gym ID | `Isaac-Velocity-Rough-Anymal-D-v0` |
| Play Gym ID | `Isaac-Velocity-Rough-Anymal-D-Play-v0` |
| Terrain | Procedural rough terrain (6 sub-terrain types with curriculum) |
| Base class chain | `AnymalDRoughEnvCfg` -> `LocomotionVelocityRoughEnvCfg` -> `ManagerBasedRLEnvCfg` |

The rough env is the canonical ANYmal D locomotion task. It uses a terrain generator with curriculum progression and includes a height scanner for terrain perception.

---

## 2. Robot Specs

| Parameter | Value |
|---|---|
| Mass | ~50 kg (nominal) |
| DOF | 12 (4 legs x 3 joints: HAA, HFE, KFE) |
| Leg length | ~0.55 m (upper + lower) |
| Init height | 0.6 m |
| Actuator model | LSTM actuator net (ANYdrive 3.0, re-used from ANYmal C) |
| Saturation effort | 120.0 Nm |
| Effort limit | 80.0 Nm |
| Velocity limit | 7.5 rad/s |
| PD gains | Kp=40.0, Kd=5.0 (DC motor fallback) |
| Self-collisions | Enabled |
| Solver iters | Position: 4, Velocity: 0 |
| Soft joint pos limit factor | 0.95 |

Default joint positions:

| Joint group | Init pos (rad) |
|---|---|
| `.*HAA` | 0.0 |
| `.*F_HFE` (front hip) | 0.4 |
| `.*H_HFE` (hind hip) | -0.4 |
| `.*F_KFE` (front knee) | -0.8 |
| `.*H_KFE` (hind knee) | 0.8 |

---

## 3. Observation Space

**Total dimension: 235** (48 proprioceptive + 187 height scan).

| Observation | Dim | Noise | Notes |
|---|---|---|---|
| `base_lin_vel` | 3 | U(-0.1, 0.1) | Base linear velocity in body frame |
| `base_ang_vel` | 3 | U(-0.2, 0.2) | Base angular velocity in body frame |
| `projected_gravity` | 3 | U(-0.05, 0.05) | Gravity vector in body frame |
| `velocity_commands` | 3 | None | Commanded (vx, vy, wz) |
| `joint_pos` | 12 | U(-0.01, 0.01) | Relative joint positions |
| `joint_vel` | 12 | U(-1.5, 1.5) | Relative joint velocities |
| `actions` | 12 | None | Previous actions |
| `height_scan` | 187 | U(-0.1, 0.1) | Ray-cast height map, clipped to (-1.0, 1.0) |

Height scanner configuration:
- Grid resolution: 0.1 m
- Grid size: 1.6 m x 1.0 m (17 x 11 = 187 points)
- Offset: (0, 0, 20) m above base (rays cast downward)
- Alignment: yaw-aligned (rotates with robot heading)
- Update period: decimation x dt = 0.02 s (50 Hz)

Observation settings:
- `enable_corruption = True` (additive uniform noise during training)
- `concatenate_terms = True`

---

## 4. Action Space

| Parameter | Value |
|---|---|
| Action type | Joint position targets |
| Dimension | 12 |
| Scale | 0.5 |
| Offset | Default joint positions (`use_default_offset=True`) |
| Joint names | `[".*"]` (all 12 joints) |

Actions are position offsets scaled by 0.5 and added to default standing pose.

---

## 5. Reward Structure

| Reward term | Weight | Function | Notes |
|---|---|---|---|
| `track_lin_vel_xy_exp` | **+1.0** | exp(-error^2/0.25) | Primary task: track xy velocity |
| `track_ang_vel_z_exp` | **+0.5** | exp(-error^2/0.25) | Track yaw rate |
| `feet_air_time` | **+0.125** | air time bonus | Threshold=0.5s, feet=`.*FOOT` |
| `lin_vel_z_l2` | **-2.0** | L2 vertical velocity | Penalize bouncing |
| `ang_vel_xy_l2` | **-0.05** | L2 roll/pitch rate | Penalize body rotation |
| `dof_torques_l2` | **-1.0e-5** | L2 joint torques | Energy efficiency |
| `dof_acc_l2` | **-2.5e-7** | L2 joint accelerations | Smooth motion |
| `action_rate_l2` | **-0.01** | L2 action rate | Smooth actions |
| `undesired_contacts` | **-1.0** | thigh contacts > 1.0N | Bodies: `.*THIGH` |
| `flat_orientation_l2` | **0.0** | L2 orientation error | **Disabled** for rough terrain (robot must tilt on slopes) |
| `dof_pos_limits` | **0.0** | joint limit violation | Disabled |

Note: The rough env intentionally disables `flat_orientation_l2` (weight=0.0) since the robot needs to adapt its body orientation to uneven terrain.

---

## 6. Command Ranges

| Parameter | Value |
|---|---|
| `lin_vel_x` | [-1.0, 1.0] m/s |
| `lin_vel_y` | [-1.0, 1.0] m/s |
| `ang_vel_z` | [-1.0, 1.0] rad/s |
| `heading` | [-pi, pi] rad |
| Resampling interval | 10.0 s (fixed) |
| Standing envs fraction | 0.02 (2%) |
| Heading envs fraction | 1.0 (100%) |
| Heading command | True |
| Heading control stiffness | 0.5 |

---

## 7. Key Thresholds

| Parameter | Value |
|---|---|
| Sim dt | 0.005 s (200 Hz physics) |
| Decimation | 4 (policy at 50 Hz) |
| Episode length | 20.0 s |
| Feet air time threshold | 0.5 s |
| Undesired contact threshold | 1.0 N |
| Illegal contact threshold (termination) | 1.0 N on base |
| Terrain friction (static) | 1.0 |
| Terrain friction (dynamic) | 1.0 |
| Max init terrain level | 5 |
| Num envs (training) | 4096 |
| Env spacing | 2.5 m |

---

## 8. Domain Randomization

### Startup (once per env)

| Event | Parameters |
|---|---|
| Physics material | static_friction=0.8, dynamic_friction=0.6, restitution=0.0 (64 buckets, **not** randomized -- range is degenerate) |
| Base mass | Add U(-5.0, +5.0) kg to base body |
| Base COM offset | x: U(-0.05, 0.05), y: U(-0.05, 0.05), z: U(-0.01, 0.01) m |

### Reset (every episode reset)

| Event | Parameters |
|---|---|
| External force/torque | force=(0,0), torque=(0,0) -- effectively disabled |
| Root state | pos: U(-0.5,0.5) xy, yaw: U(-pi,pi); vel: U(-0.5,0.5) all axes |
| Joint reset | position scale U(0.5, 1.5) of default, velocity=0 |

### Interval (during episode)

| Event | Parameters |
|---|---|
| Push robot | Every 10-15s, set velocity x,y: U(-0.5, 0.5) m/s |

### Terrain Curriculum

The rough env uses a terrain curriculum (`terrain_levels_vel`) that progresses robots to harder terrain as they improve. Terrain difficulty increases across rows.

---

## 9. Terrain Configuration

`ROUGH_TERRAINS_CFG` -- procedurally generated terrain grid:

| Parameter | Value |
|---|---|
| Tile size | 8.0 x 8.0 m |
| Border width | 20.0 m |
| Grid layout | 10 rows x 20 columns (200 tiles) |
| Horizontal scale | 0.1 m |
| Vertical scale | 0.005 m |
| Slope threshold | 0.75 |

### Sub-terrain types

| Type | Proportion | Key parameters |
|---|---|---|
| `pyramid_stairs` | 20% | Step height 0.05-0.23 m, width 0.3 m, platform 3.0 m |
| `pyramid_stairs_inv` (inverted) | 20% | Step height 0.05-0.23 m, width 0.3 m, platform 3.0 m |
| `boxes` (random grid) | 20% | Grid width 0.45 m, height 0.05-0.2 m, platform 2.0 m |
| `random_rough` | 20% | Noise range 0.02-0.10, step 0.02 |
| `hf_pyramid_slope` | 10% | Slope range 0.0-0.4, platform 2.0 m |
| `hf_pyramid_slope_inv` | 10% | Slope range 0.0-0.4, platform 2.0 m |

---

## 10. Training Config
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

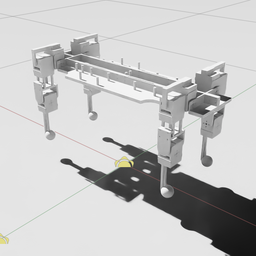
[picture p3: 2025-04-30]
part_files/V4/.thumbs/256x256/harold_3.usd.png

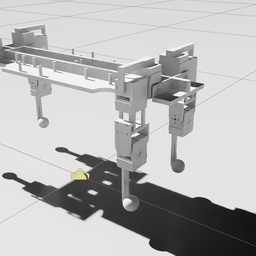
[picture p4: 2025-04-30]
part_files/V4/.thumbs/256x256/harold_6.usd.png

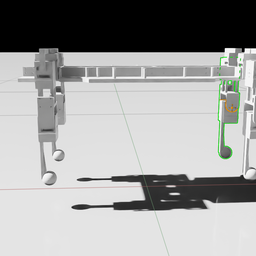
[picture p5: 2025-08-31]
part_files/V4/.thumbs/256x256/harold_8.usd.png

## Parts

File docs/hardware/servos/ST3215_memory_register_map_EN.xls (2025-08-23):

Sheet: Sheet2
ST3215 Memory Table Parsing -V3.7
 |  | No-load speed（RPM） |  | 49.776 |  | Test voltage (V) |  |  | 7.4V
 |  | No-load speed (step/second) |  | 3400 |  | No-load Current (mA) |  |  | 150
 |  | Maximum effective angle (degree) |  | 360 | Supports multi-turn large-angle control, does not retain revolution count after power loss.
 |  | Resolution (step) |  | 4096
 |  | Minimum resolution angle (degree/step) |  | 0.087890625 |  | Electronic dead zone (degree) |  |  | 0.17578125
 |  | Acceleration (degree/s^2) |  | 8.7890625
 | Memory First Address |  | Function | Number of Bytes | Initial Value | Storage Area | Permission | Minimum Value | Maximum Value | Unit | Value Parsing
0x | DEC | HEX |  | Little-endian |  |  |  |  |  |  | If the functional address uses a two-byte data format, with the low-order byte at the preceding address and the high-order byte at the succeeding address.
0 | 0 | 0 | Firmware major version number | 1 | 3 | EPROM | read only | -1 | -1
1 | 1 | 1 | Firmware minor version number | 1 | 7 | EPROM | read only | -1 | -1
3 | 3 | 3 | Servo major version number | 1 | 9 | EPROM | read only | -1 | -1
4 | 4 | 4 | Servo minor version number | 1 | 3 | EPROM | read only | -1 | -1
5 | 5 | 0x5 | ID | 1 | 1 | EPROM | read/write | 0 | 253 | Baud | A unique identification code on the bus, with no duplicate ID numbers allowed on the same bus. ID number 254 (0xFE) is the broadcast ID, and broadcasts do not receive response packets.
6 | 6 | 0x6 | Baudrate | 1 | 0 | EPROM | read/write | 0 | 7 | None | 0-7 respectively represent baud rates as follows: 1000000, 500000, 250000, 128000, 115200, 76800, 57600, 38400
7 | 7 | 0x7 | Return delay | 1 | 0 | EPROM | read/write | 0 | 254 | 2us | The minimum unit is 2us, and the maximum allowable setting for response delay is 254*2=508us
8 | 8 | 0x8 | Response status level | 1 | 1 | EPROM | read/write | 0 | 1 | None | 0: Except for read and PING instructions, other instructions do not return response packets. 1: Return response packets for all instructions
9 | 9 | 0x9 | Minimum angle | 2 | 0 | EPROM | read/write | -32766 | -- | Step | Set the minimum value limit for the motion range, which should be smaller than the maximum angle limit. When performing multi-turn absolute position control, this value is set to 0.
B | 11 | 0xB | Maximum angle | 2 | 4095 | EPROM | read/write | -- | 32767 | Step | Set the maximum value limit for the motion range, which should be greater than the minimum angle limit. When performing multi-turn absolute position control, this value is set to 0.
D | 13 | 0xD | Maximum temperature | 1 | 70 | EPROM | read/write | 0 | 100 | °C | The maximum operating temperature limit, when set to 70, means the maximum temperature is 70 degrees Celsius, with a precision setting of 1 degree Celsius.
E | 14 | 0xE | Maximum input voltage | 1 | 80 | EPROM | read/write | 0 | 254 | 0.1V | If the maximum input voltage is set to 80, then the maximum operating voltage limit is 8.0V, with a precision setting of 0.1V.
F | 15 | 0xF | Minimum input voltage | 1 | 40 | EPROM | read/write | 0 | 254 | 0.1V | If the minimum input voltage is set to 40, then the minimum operating voltage limit is 4.0V, with a precision setting of 0.1V.
10 | 16 | 0x10 | Maximum torque | 2 | 1000 | EPROM | read/write | 0 | 1000 | 0.10% | Set the maximum output torque limit for the servo motor, where 1000 corresponds to 100% of the locked-rotor torque. Assign this value to address 48 upon power-up as the torque limit.
12 | 18 | 0x12 | Phase | 1 | 12 | EPROM | read/write | 0 | 254 | None | Special function byte, do not modify unless there are specific requirements. Please refer to the special byte bit analysis for further details.
13 | 19 | 0x13 | Unloading conditions | 1 | 44 | EPROM | read/write | 0 | 254 | None | Bit0 Bit1 Bit2 Bit3 Bit4 Bit5 set corresponding bit to 1 to enable the corresponding protection. Voltage Sensor Temperature Current Angle Overload set corresponding bit to 0 to disable the corresponding protection
14 | 20 | 0x14 | LED alarm conditions | 1 | 47 | EPROM | read/write | 0 | 254 | None | Bit0 Bit1 Bit2 Bit3 Bit4 Bit5 set the corresponding bit to 1 to enable flashing LED. Voltage Sensor Temperature Current Angle Overload set corresponding bit to 0 to disable the corresponding protection
15 | 21 | 0x15 | Position loop P (Proportional) coefficient | 1 | 32 | EPROM | read/write | 0 | 254 | None | Proportional coefficient of control motor
16 | 22 | 0x16 | Position loop D (Differential) coefficient | 1 | 32 | EPROM | read/write | 0 | 254 | None | Differential coefficient of control motor
17 | 23 | 0x17 | Position loop I (Integral) coefficient | 1 | 0 | EPROM | read/write | 0 | 254 | None | Integral coefficient of the control motor
18 | 24 | 0x18 | Minimum starting force | 2 | 16 | EPROM | read/write | 0 | 1000 | 0.1% | Set the minimum output startup torque for the servo, where 1000 corresponds to 100% of the locked-rotor torque.
1A | 26 | 0x1A | Clockwise insensitive zone | 1 | 1 | EPROM | read/write | 0 | 32 | Step | The minimum unit is one minimum resolution angle.
1B | 27 | 0x1B | Anti-clockwise insensitive zone | 1 | 1 | EPROM | read/write | 0 | 32 | Step | The minimum unit is a minimum resolution angle.
1C | 28 | 0x1C | Protection current | 2 | 500 | EPROM | read/write | 0 | 511 | 6.5mA | The maximum settable current is 500 * 6.5mA= 3250mA.
1E | 30 | 0x1E | Angle resolution | 1 | 1 | EPROM | read/write | 1 | 3 | None | For the amplification factor of the minimum resolution angle (degree/step) of the sensor, modifying this value can expand the number of control range. When performing the multi-turn control, you need to modify the parameter at address 0x12 by setting BIT4 to 1. This modification will result in the current position feedback value being adjusted to reflect the larger angle feedback.
1F | 31 | 0x1F | Position correction | 2 | 0 | EPROM | read/write | -2047 | 2047 | Step | BIT11 is the direction bit, indicating the positive and negative direction, and other bits can indicate the range of 0-2047 steps.
21 | 33 | 0x21 | Operation mode | 1 | 0 | EPROM | read/write | 0 | 3 | None | 0: position servo mode 1: motor constant speed mode, controlled by parameter 0x2E running speed parameter, the highest bit BIT15 is direction bit. 2: PWM open-loop speed regulation mode, controlled by parameter 0x2Cthe running time parameter, BIT10 is direction bit 3: step servo mode, and the target position of parameter 0x2A is used to indicate the number of steps, and the highest bit BIT15 is the direction bit. When working In mode 3, the minimum and maximum angle limits of 0x9 and 0xB must be set to 0. Otherwise, it is impossible to step indefinitely.
22 | 34 | 0x22 | Protection torque | 1 | 20 | EPROM | read/write | 0 | 100 | 1.0% | Output torque after entering overload protection. If 20 is set, it means 20% of the maximum torque.
23 | 35 | 0x23 | Protection time | 1 | 200 | EPROM | read/write | 0 | 254 | 10ms | The duration for which the current load output exceeds the overload torque and remains is represented by a value, such as 200, which indicates 2 seconds. The maximum value that can be set is 2.5 seconds.
24 | 36 | 0x24 | Overload torque | 1 | 80 | EPROM | read/write | 0 | 100 | 1.0% | The maximum torque threshold for starting the overload protection time countdown can be represented by a value, such as 80, indicating 80% of the maximum torque.
25 | 37 | 0x25 | Speed closed-loop proportional (P) coefficient | 1 | 10 | EPROM | read/write | 0 | 100 | None | Proportional coefficient of speed loop in motor constant speed mode (mode 1)
26 | 38 | 0x26 | Overcurrent protection time | 1 | 200 | EPROM | read/write | 0 | 254 | 10ms | The maximum setting is 254 * 10ms = 2540ms.
27 | 39 | 0x27 | Velocity closed-loop integral (I) coefficient | 1 | 10 | EPROM | read/write | 0 | 254 | 1/10 | In the motor constant speed mode (mode 1), the speed loop integral coefficient (change note: the speed closed loop I integral coefficient is reduced by 10 times compared with version 3.6).
28 | 40 | 0x28 | Torque switch | 1 | 0 | SRAM | read/write | 0 | 128 | None | Write 0: disable the torque output; Write 1: enable the torque output; Write 128: Arbitrary current position correction to 2048.
29 | 41 | 0x29 | Acceleration | 1 | 0 | SRAM | read/write | 0 | 254 | 100 step/s^2 | If set to 10, it corresponds to an acceleration and deceleration rate of 1000 steps per second squared.
2A | 42 | 0x2A | Target location | 2 | 0 | SRAM | read/write | -30719 | 30719 | Step | Each step corresponds to the minimum resolution angle, and it is used in absolute position control mode. The maximum number of steps corresponds to the maximum effective angle.
2C | 44 | 0x2C | Operation time | 2 | 0 | SRAM | read/write | 0 | 1000 | 0.10% | In the PWM open-loop speed control mode, the value range is from 50 to 1000, and BIT10 serves as the direction bit.
2E | 46 | 0x2E | Operation speed | 2 | 0 | SRAM | read/write | 0 | 3400 | step/s | Number of steps per unit time (per second), 50 steps per second = 0.732 RPM (revolutions per minute)
30 | 48 | 0x30 | Torque limit | 2 | 1000 | SRAM | read/write | 0 | 1000 | 1.0% | The initial value of power-on will be assigned by the maximum torque (0x10), which can be modified by the user to control the output of the maximum torque.
37 | 55 | 0x37 | Lock flag | 1 | 0 | SRAM | read/write | 0 | 1 | None | Writing 0: Disables the write lock, allowing values written to the EPROM address to be saved even after power loss. Writing 1: Enables the write lock, preventing values written to the EPROM address from being saved after power loss.
38 | 56 | 0x38 | Current location | 2 | 0 | SRAM | read only | -1 | -1 | Step | Feedback the number of steps in the current position, each step is a minimum resolution angle; Absolute position control mode, the maximum value corresponds to the maximum effective angle.
3A | 58 | 0x3A | Current speed | 2 | 0 | SRAM | read only | -1 | -1 | step/s | Feedback the current speed of motor rotation and the number of steps in unit time (per second).
3C | 60 | 0x3C | Current load | 2 | 0 | SRAM | read only | -1 | -1 | 0.1% | The voltage duty cycle of the current control output driving motor.
3E | 62 | 0x3E | Current voltage | 1 | 0 | SRAM | read only | -1 | -1 | 0.1V | Current servo operation voltage
3F | 63 | 0x3F | Current temperature | 1 | 0 | SRAM | read only | -1 | -1 | °C | Current servo internal operating temperature
40 | 64 | 0x40 | Asynchronous write flag | 1 | 0 | SRAM | read only | -1 | -1 | None | The flag bit for using asynchronous write instructions
41 | 65 | 0x41 | Servo status | 1 | 0 | SRAM | read only | -1 | -1 | None | Bit0 Bit1 Bit2 Bit3 Bit4 Bit5 the corresponding bit is set to 1 to indicate that the corresponding error occurs, Voltage Sensor Temperature Current Angle Overload the corresponding bit is set to 0 to indicate that there is no corresponding error.
42 | 66 | 0x42 | Move flag | 1 | 0 | SRAM | read only | -1 | -1 | None | The sign of the servo is 1 when it is moving, and 0 when it is stopped.
45 | 69 | 0x45 | Current current | 2 | 0 | SRAM | read only | -1 | -1 | 6.5mA | The maximum measurable current is 500 * 6.5mA= 3250mA.

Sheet: Sheet1
 | STS3215内存表参数解析 -V3.7
 |  | 空载速度（RPM） |  | 49.776 |  | 测试电压(V) |  |  | 7.4V
 |  | 空载速度（步/秒） |  | 3400 |  | 空载电流（mA) |  |  | 150
 |  | 最大有效角度（度） |  | 360 | 支持多圈大角度控制，掉电不保存圈数
 |  | 解析度（步） |  | 4096
 |  | 最小分辨角度（度/步） |  | 0.087890625 |  | 电子死区（度） |  |  | 0.17578125
 |  | 加速度（度/s^2） |  | 8.7890625
 | 内存首地址 |  | 功能 | 字节数 | 初始值 | 存储区 | 权限 | 最小取值 | 最大取值 | 单位 | 取值解析
0x | DEC | HEX |  | 低在前 高在后 |  |  |  |  |  |  | 如果功能地址采用两个字节数的数据，低位字节在前面地址，高位字节在后面地址
0 | 0 | 0 | 固件主版本号 | 1 | 3 | EPROM | 只读 | -1 | -1
1 | 1 | 1 | 固件次版本号 | 1 | 7 | EPROM | 只读 | -1 | -1
3 | 3 | 3 | 舵机主版本号 | 1 | 9 | EPROM | 只读 | -1 | -1
4 | 4 | 4 | 舵机次版本号 | 1 | 3 | EPROM | 只读 | -1 | -1
5 | 5 | 0x5 | ID | 1 | 1 | EPROM | 读写 | 0 | 253 | 号 | 总线上唯一的身份识别码，同一总线不可出现重复ID号 254号(OxFE)为广播ID，广播不返回应答包
6 | 6 | 0x6 | 波特率 | 1 | 0 | EPROM | 读写 | 0 | 7 | 无 | 0-7分别代表波特率如下 1000000，500000，250000，128000，115200，76800，57600，38400
7 | 7 | 0x7 | 返回延时 | 1 | 0 | EPROM | 读写 | 0 | 254 | 2us | 最小单位为2us,最大可设置返回延时 254*2=508us
8 | 8 | 0x8 | 应答状态级别 | 1 | 1 | EPROM | 读写 | 0 | 1 | 无 | 0:除读指令与PING指令外其它指令不返回应答包 1:对所有指令返回应答包
9 | 9 | 0x9 | 最小角度限制 | 2 | 0 | EPROM | 读写 | -32766 | -- | 步 | 设置运动行程最小值限制，取值小于最大角度限制，多圈绝对位置控制时此值为0
B | 11 | 0xB | 最大角度限制 | 2 | 4095 | EPROM | 读写 | -- | 32767 | 步 | 设置运动行程最大值限制，取值大于最小角度限制，多圈绝对位置控制时此值为0
D | 13 | 0xD | 最高温度上限 | 1 | 70 | EPROM | 读写 | 0 | 100 | °C | 最高工作温度限制，如设置为70 则最高温度为70摄氏度，设置精度为1摄氏度
E | 14 | 0xE | 最高输入电压 | 1 | 80 | EPROM | 读写 | 0 | 254 | 0.1V | 最高输入电压如设置为80，则最高工作电压限制为8.0V，设置精度为0.1V
F | 15 | 0xF | 最低输入电压 | 1 | 40 | EPROM | 读写 | 0 | 254 | 0.1V | 最低输入电压如设置为40，则最低工作电压限制为4.0V，设置精度为0.1V
10 | 16 | 0x10 | 最大扭矩 | 2 | 1000 | EPROM | 读写 | 0 | 1000 | 0.10% | 设置舵机的最大输出扭矩限制，设1000 = 100% * 堵转扭力， 上电赋值给48号地址转矩限制
12 | 18 | 0x12 | 相位 | 1 | 12 | EPROM | 读写 | 0 | 254 | 无 | 特殊功能字节，无特别需求不可修改,详见特殊字节位解析
13 | 19 | 0x13 | 卸载条件 | 1 | 44 | EPROM | 读写 | 0 | 254 | 无 | Bit0 Bit1 Bit2 Bit3 Bit4 Bit5 对应位设置1为开启相应保护 电压 传感器 温度 电流 角度 过载 对应位设置0为关闭相应保护
14 | 20 | 0x14 | LED报警条件 | 1 | 47 | EPROM | 读写 | 0 | 254 | 无 | Bit0 Bit1 Bit2 Bit3 Bit4 Bit5 对应位设置1为开启闪灯报警 电压 传感器 温度 电流 角度 过载 对应位设置0为关闭闪灯报警
15 | 21 | 0x15 | 位置环P 比例系数 | 1 | 32 | EPROM | 读写 | 0 | 254 | 无 | 控制电机的比例系数
16 | 22 | 0x16 | 位置环D 微分系数 | 1 | 32 | EPROM | 读写 | 0 | 254 | 无 | 控制电机的微分系数
17 | 23 | 0x17 | 位置环I 积分系数 | 1 | 0 | EPROM | 读写 | 0 | 254 | 无 | 控制电机的积分系数
18 | 24 | 0x18 | 最小启动力 | 2 | 16 | EPROM | 读写 | 0 | 1000 | 0.1% | 设置舵机的最小输出启动扭矩，设1000 = 100% * 堵转扭力
1A | 26 | 0x1A | 顺时针不灵敏区 | 1 | 1 | EPROM | 读写 | 0 | 32 | 步 | 最小单位为一个最小分辨角度
1B | 27 | 0x1B | 逆时针不灵敏区 | 1 | 1 | EPROM | 读写 | 0 | 32 | 步 | 最小单位为一个最小分辨角度
1C | 28 | 0x1C | 保护电流 | 2 | 500 | EPROM | 读写 | 0 | 511 | 6.5mA | 最大可设置电流为 500 * 6.5mA= 3250mA
1E | 30 | 0x1E | 角度分辨率 | 1 | 1 | EPROM | 读写 | 1 | 3 | 无 | 对传感器最小分辨角度（度/步）的放大系数，修改此值可以扩展控制圈数 多圈控制时需修改地址0x12参数BIT4置1，当前位置反馈值会被修改为大角度反馈
1F | 31 | 0x1F | 位置校正 | 2 | 0 | EPROM | 读写 | -2047 | 2047 | 步 | BIT11为方向位，表示正负方向，其他位可表示范围为0-2047步
21 | 33 | 0x21 | 运行模式 | 1 | 0 | EPROM | 读写 | 0 | 3 | 无 | 0：位置伺服模式 1：电机恒速模式,用参数0x2E运行速度参数控制，最高位BIT15为方向位 2：PWM开环调速度模式，用参数0x2C 运行时间参数控制，BIT10为方向位 3：步进伺服模式，用参数0x2A 目标位置表示步进步数，最高位BIT15为方向位 工作在模式3时，必须把0x9与0xB 最小最大角度限制设为0，否则不能无限步进
22 | 34 | 0x22 | 保护扭矩 | 1 | 20 | EPROM | 读写 | 0 | 100 | 1.0% | 进入过载保护后输出扭矩，如设20表示20%的最大扭矩
23 | 35 | 0x23 | 保护时间 | 1 | 200 | EPROM | 读写 | 0 | 254 | 10ms | 当前负载输出超过过载扭力并保持的计时时长，如设200表示2秒，最大可设2.5秒
24 | 36 | 0x24 | 过载扭矩 | 1 | 80 | EPROM | 读写 | 0 | 100 | 1.0% | 启动过载保护时间计时的最大扭力阀值，如设80表示80%的最大扭矩
25 | 37 | 0x25 | 速度闭环P比例系数 | 1 | 10 | EPROM | 读写 | 0 | 100 | 无 | 电机恒速模式（模式1）下,速度环比例系数
26 | 38 | 0x26 | 过流保护时间 | 1 | 200 | EPROM | 读写 | 0 | 254 | 10ms | 最大可设置254 * 10ms = 2540ms
27 | 39 | 0x27 | 速度闭环I积分系数 | 1 | 10 | EPROM | 读写 | 0 | 254 | 1/10 | 电机恒速模式（模式1）下,速度环积分系数 （变动备注：速度闭环I积分系数缩小10倍较3.6版本）
28 | 40 | 0x28 | 扭矩开关 | 1 | 0 | SRAM | 读写 | 0 | 128 | 无 | 写0：关闭扭力输出； 写1：打开扭力输出；写128：任意当前位置较正为2048
29 | 41 | 0x29 | 加速度 | 1 | 0 | SRAM | 读写 | 0 | 254 | 100步/s^2 | 如设置为10 则按1000步每秒平方的加减速度变速
2A | 42 | 0x2A | 目标位置 | 2 | 0 | SRAM | 读写 | -30719 | 30719 | 步 | 每步为一个最小分辨角度，绝对位置控制方式，最大对应最大有效角度
2C | 44 | 0x2C | 运行时间 | 2 | 0 | SRAM | 读写 | 0 | 1000 | 0.10% | PWM开环调速度模式下，取值范围50-1000，BIT10为方向位
2E | 46 | 0x2E | 运行速度 | 2 | 0 | SRAM | 读写 | 0 | 3400 | 步/s | 单位时间（每秒）内运动的步数，50步/秒= 0.732 RPM(圈每分钟）
30 | 48 | 0x30 | 转矩限制 | 2 | 1000 | SRAM | 读写 | 0 | 1000 | 1.0% | 上电初始值会由最大扭矩（0x10）赋值，用户可程序修改此值来控制最大扭矩的输出
37 | 55 | 0x37 | 锁标志 | 1 | 0 | SRAM | 读写 | 0 | 1 | 无 | 写0关闭写入锁，写入EPROM地址的值掉电保存 写1打开写入锁，写入EPROM地址的值掉电不保存
38 | 56 | 0x38 | 当前位置 | 2 | 0 | SRAM | 只读 | -1 | -1 | 步 | 反馈当前所处位置的步数，每步为一个最小分辨角度；绝对位置控制方式，最大值对应最大有效角度
3A | 58 | 0x3A | 当前速度 | 2 | 0 | SRAM | 只读 | -1 | -1 | 步/s | 反馈当前电机转动的速度，单位时间（每秒）内运动的步数
3C | 60 | 0x3C | 当前负载 | 2 | 0 | SRAM | 只读 | -1 | -1 | 0.1% | 当前控制输出驱动电机的电压占空比
3E | 62 | 0x3E | 当前电压 | 1 | 0 | SRAM | 只读 | -1 | -1 | 0.1V | 当前舵机工作电压
3F | 63 | 0x3F | 当前温度 | 1 | 0 | SRAM | 只读 | -1 | -1 | °C | 当前舵机内部工作温度
40 | 64 | 0x40 | 异步写标志 | 1 | 0 | SRAM | 只读 | -1 | -1 | 无 | 采用异步写指令时，标志位
41 | 65 | 0x41 | 舵机状态 | 1 | 0 | SRAM | 只读 | -1 | -1 | 无 | Bit0 Bit1 Bit2 Bit3 Bit4 Bit5 对应位被置1表示相应错误出现 电压 传感器 温度 电流 角度 过载 对应位0为无相应该错误
42 | 66 | 0x42 | 移动标志 | 1 | 0 | SRAM | 只读 | -1 | -1 | 无 | 舵机在运动时标志为1，舵机停止时为0
45 | 69 | 0x45 | 当前电流 | 2 | 0 | SRAM | 只读 | -1 | -1 | 6.5mA | 最大可测量电流为 500 * 6.5mA= 3250mA

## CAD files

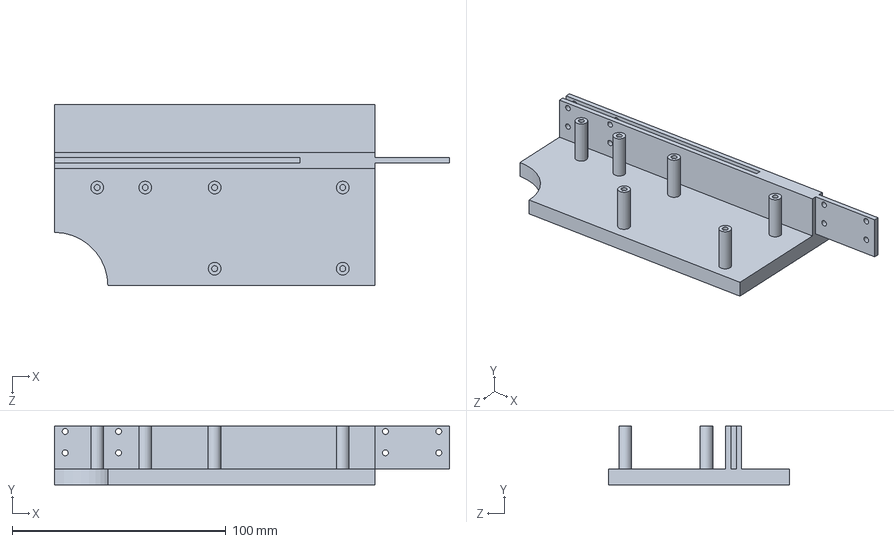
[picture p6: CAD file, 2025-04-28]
part_files/V4/body files/(left mirror)body middle front right.SLDPRT
185.0 x 27.5 x 85.0 mm

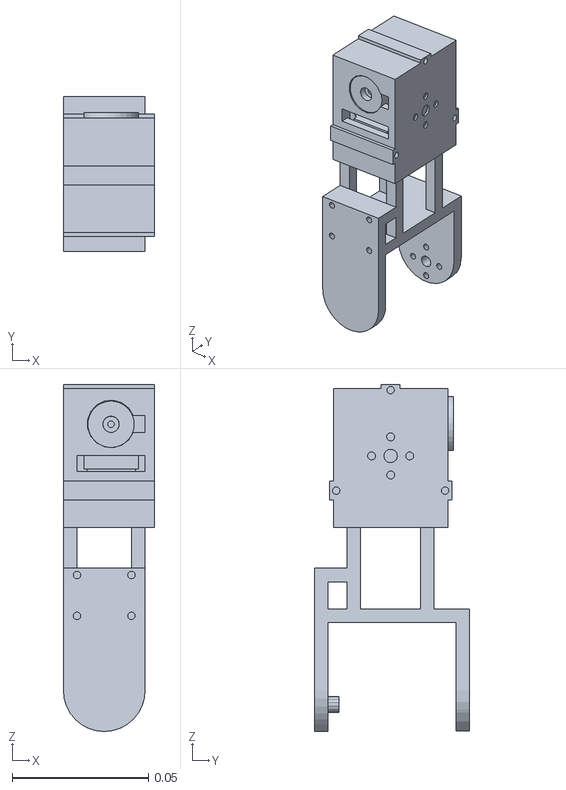
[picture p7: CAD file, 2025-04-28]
part_files/V4/Corrected_Meshes/right_thigh.stl
0.0335 x 0.057 x 0.127

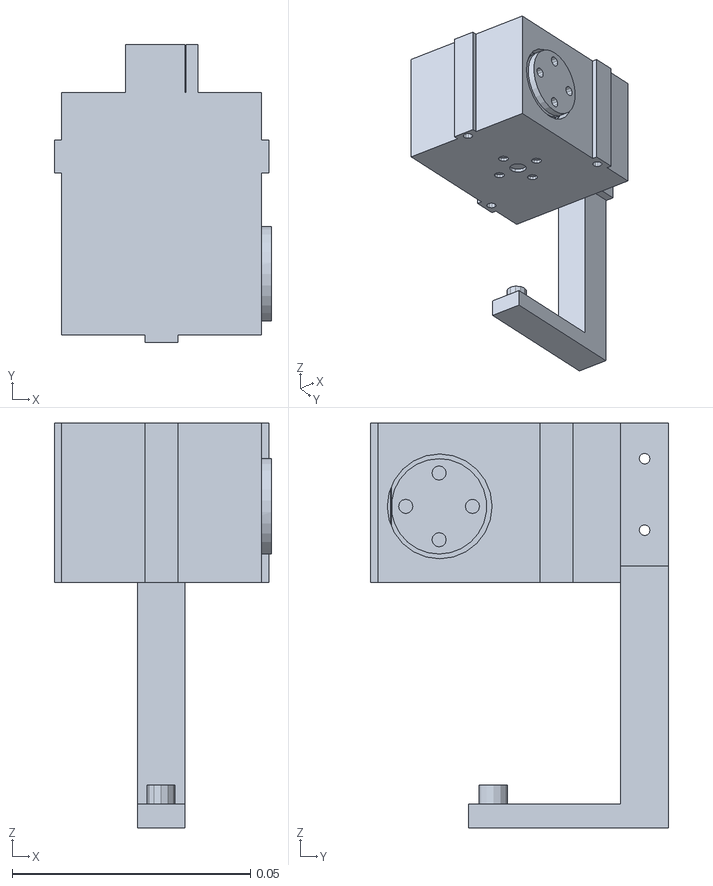
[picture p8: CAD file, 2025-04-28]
part_files/V4/Harold_URDF_Export_2/meshes/fr_shoulder.STL
0.0456 x 0.0625 x 0.085

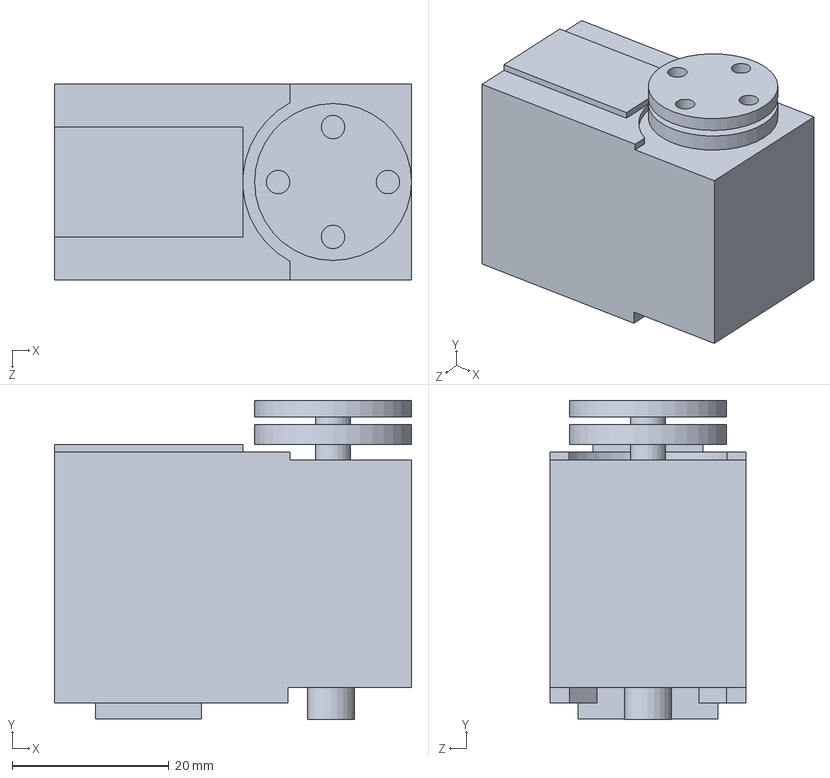
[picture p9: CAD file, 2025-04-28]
part_files/V4/leg files/STS3215.SLDPRT
45.5 x 40.7 x 25.0 mm

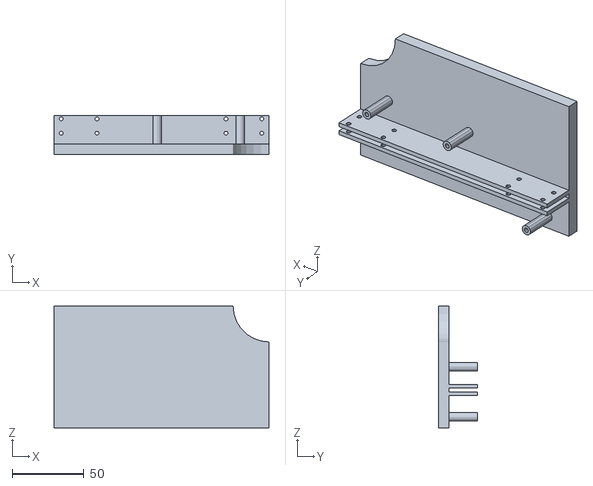
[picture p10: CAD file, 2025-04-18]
part_files/V4/STL files/body/body middle back left.STL
150.0 x 27.5 x 85.0

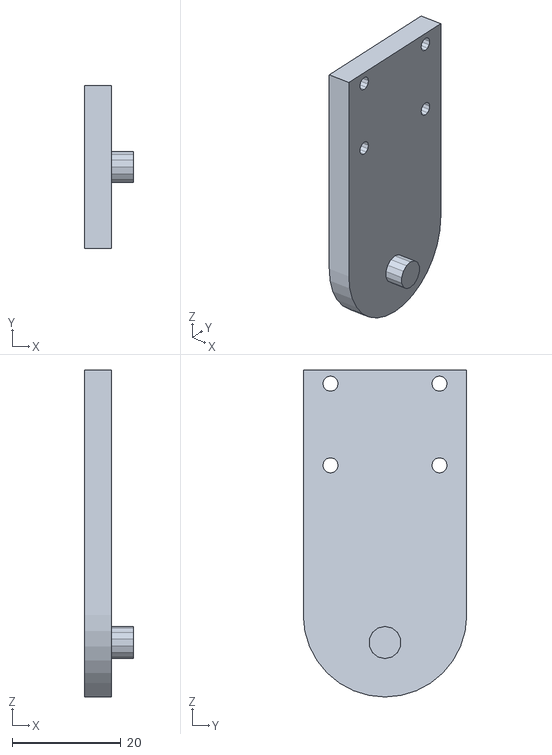
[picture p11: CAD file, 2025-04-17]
part_files/V4/STL files/legs/L Thigh Connector.STL
9.00 x 30.0 x 60.0

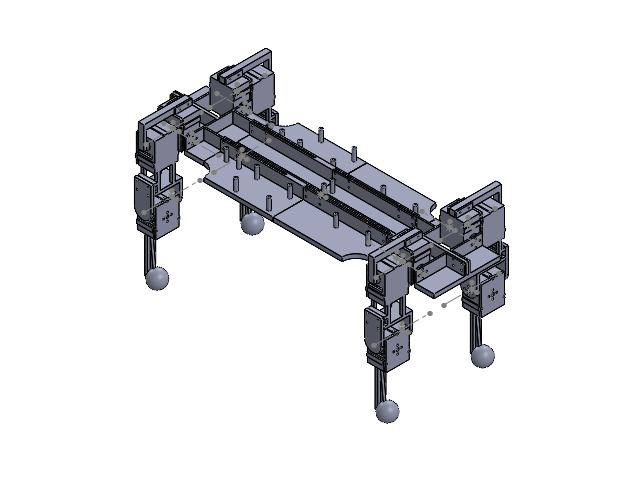
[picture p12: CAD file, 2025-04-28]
part_files/V4/Harold.SLDASM
body front
(left mirror)body middle back right
(left mirror)body middle front right
body back
body back 2
body front 2
body middle back right
body middle front right
(Left Mirror)STS3215 x 6
(Left Mirror)Ball Bearing x 6
(Left Mirror)R Shoulder x 2
(Left Mirror)R Shoulder Arm x 2
(Left Mirror)Servo Lid x 6
(Left Mirror)R Thigh x 2
(Left Mirror)R Thigh Connector x 2
(Left Mirror)R Calf x 2
STS3215 x 6
Ball Bearing x 6
R Shoulder x 2
R Shoulder Arm x 2
Servo Lid x 6
R Thigh x 2
R Thigh Connector x 2
R Calf x 2

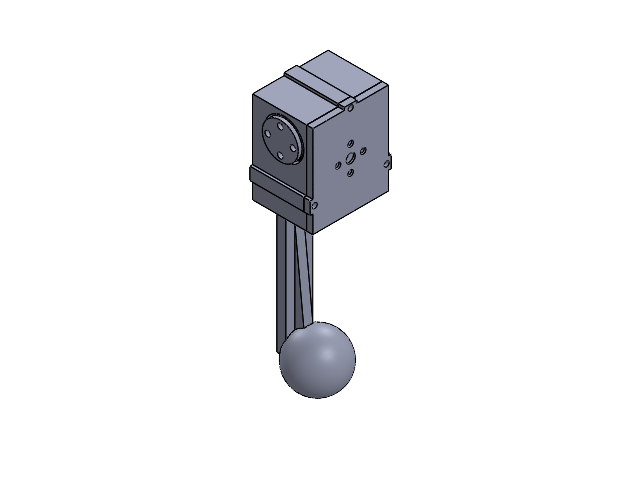
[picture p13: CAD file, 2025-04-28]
part_files/V4/subassemblies/right_calf.SLDASM
STS3215
Ball Bearing
R Calf
Servo Lid

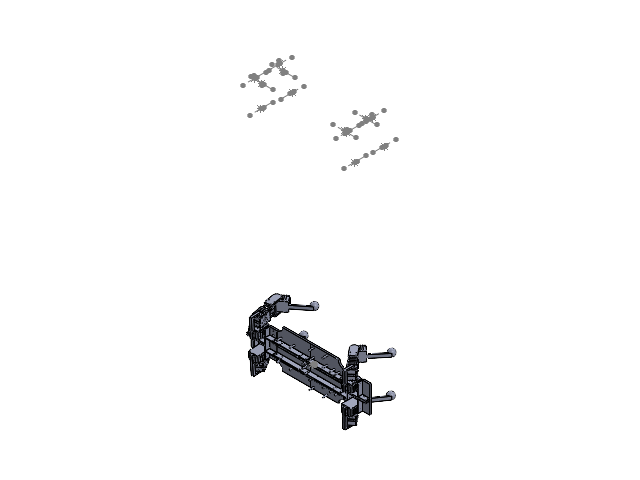
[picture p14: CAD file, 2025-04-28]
part_files/V4/full_body.SLDASM
body front
(left mirror)body middle back right
(left mirror)body middle front right
body back
body back 2
body front 2
body middle back right
body middle front right
STS3215 x 6
Ball Bearing x 6
R Calf x 2
Servo Lid x 6
R Shoulder x 2
R Shoulder Arm x 2
R Thigh x 2
R Thigh Connector x 2
(Left Mirror)STS3215 x 6
(Left Mirror)Ball Bearing x 6
(Left Mirror)R Calf x 2
(Left Mirror)Servo Lid x 6
(Left Mirror)R Shoulder x 2
(Left Mirror)R Shoulder Arm x 2
(Left Mirror)R Thigh x 2
(Left Mirror)R Thigh Connector x 2

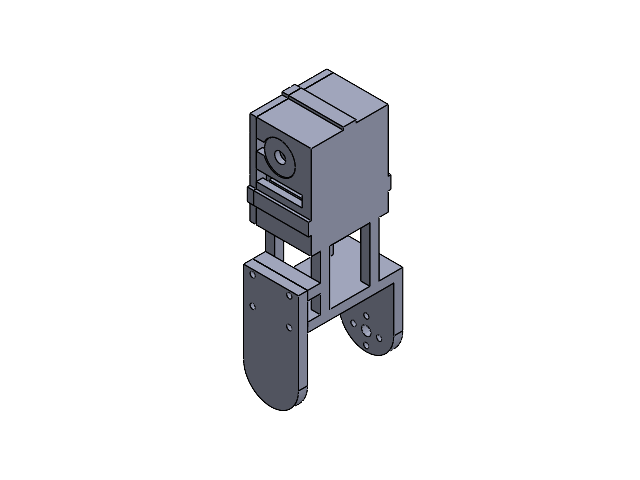
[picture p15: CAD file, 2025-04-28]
part_files/V4/subassemblies/left_thigh.SLDASM
(Left Mirror)STS3215
(Left Mirror)Ball Bearing
(Left Mirror)R Thigh
(Left Mirror)R Thigh Connector
(Left Mirror)Servo Lid

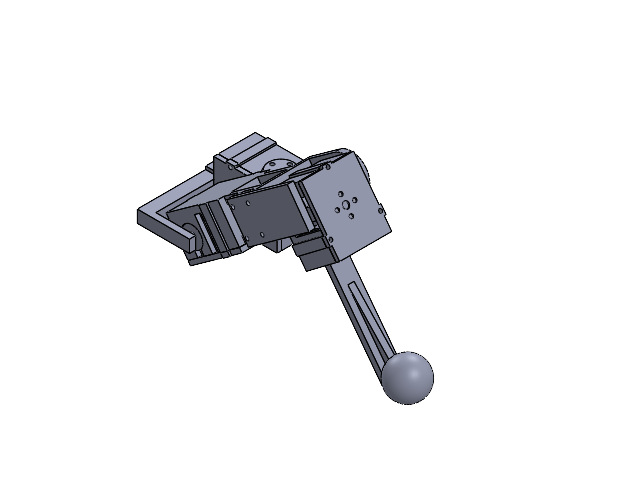
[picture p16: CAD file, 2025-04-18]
part_files/V4/Left Leg.SLDASM
(Left Mirror)STS3215 x 3
(Left Mirror)Ball Bearing x 3
(Left Mirror)R Shoulder
(Left Mirror)R Shoulder Arm
(Left Mirror)Servo Lid x 3
(Left Mirror)R Thigh
(Left Mirror)R Thigh Connector
(Left Mirror)R Calf

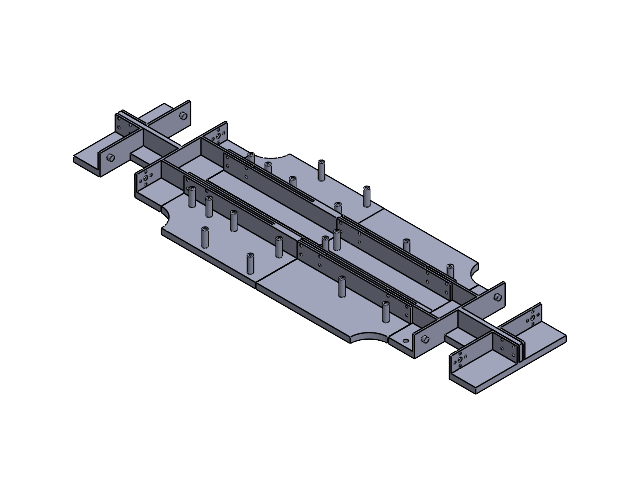
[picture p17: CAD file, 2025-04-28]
part_files/V4/subassemblies/body.SLDASM
body front
(left mirror)body middle back right
(left mirror)body middle front right
body back
body back 2
body front 2
body middle back right
body middle front right

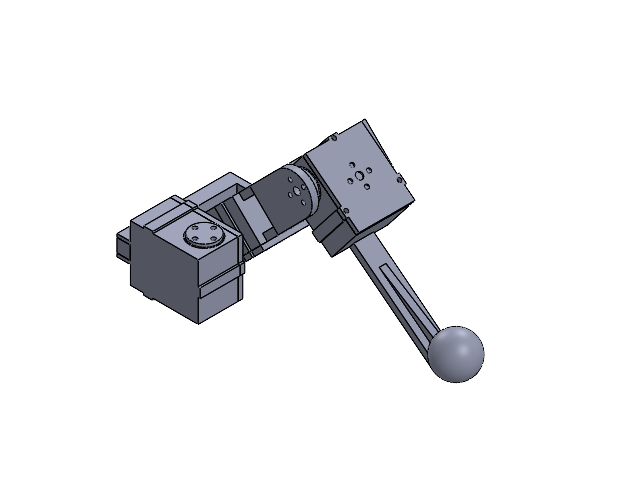
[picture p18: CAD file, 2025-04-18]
part_files/V4/Right Leg.SLDASM
STS3215 x 3
Ball Bearing x 3
R Shoulder
R Shoulder Arm
Servo Lid x 3
R Thigh
R Thigh Connector
R Calf

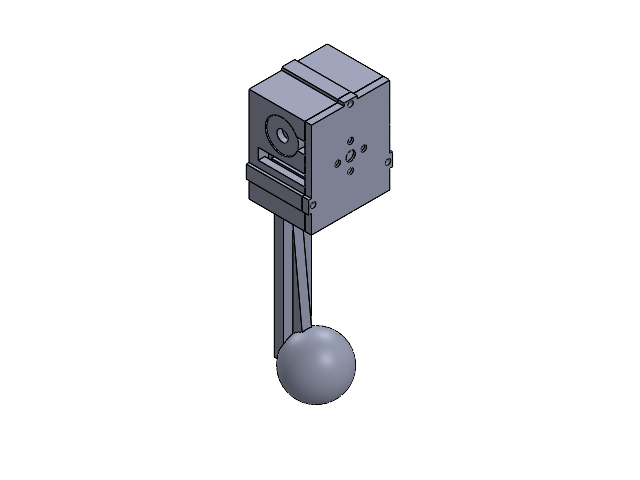
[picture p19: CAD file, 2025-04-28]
part_files/V4/subassemblies/left_calf.SLDASM
(Left Mirror)STS3215
(Left Mirror)Ball Bearing
(Left Mirror)R Calf
(Left Mirror)Servo Lid

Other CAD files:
part_files/V4/subassemblies/left_shoulder.SLDASM
part_files/V4/subassemblies/right_shoulder.SLDASM
part_files/V4/subassemblies/right_thigh.SLDASM
part_files/V4/Harold_URDF_Export/meshes/fr_thigh.STL
part_files/Old Crap/V0/Ball Bearing.SLDPRT
part_files/Old Crap/V0/Body OnlySLDASM.SLDASM
part_files/Old Crap/V0/Full Body.SLDASM
part_files/Old Crap/V0/HAROLD REFRESH/left_leg.SLDASM
part_files/Old Crap/V0/STL files/L knee bottom.STL
part_files/Old Crap/V0/STL files/L knee top.STL
part_files/Old Crap/V0/STL files/L shoulder bottom.STL
part_files/Old Crap/V0/STL files/L shoulder connector arm.STL
part_files/Old Crap/V0/STL files/L shoulder top.STL
part_files/Old Crap/V0/STL files/L thigh bottom.STL
part_files/Old Crap/V0/STL files/L thigh top.STL
part_files/Old Crap/V0/STL files/R knee bottom.STL
part_files/Old Crap/V0/STL files/R knee top.STL
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

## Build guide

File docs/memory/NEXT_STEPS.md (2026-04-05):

# Harold Next Steps

## HIGH PRIORITY — Manager-Based Walking (EXP-785 baseline)

1. **Export manager-based policy to ONNX** — Export the trained policy for hardware deployment. The existing export pipeline may need updates for the manager-based architecture (50Hz control rate, different obs/action scaling).
2. **Run autoresearch to optimize walking gait** — Use the manager-based env (`harold_mgr`) as baseline. Tune reward weights, command ranges, and training hyperparameters to improve foot clearance, step length, and gait quality.

## MEDIUM PRIORITY — Sim-to-Real Pipeline

3. **Run real-world hardware test** — Deploy the manager-based policy on the robot off the test stand. Ensure IMU recording is active. Compare sim vs real joint positions, commands, and IMU data.
4. **Sim-to-real alignment** — Compare hardware logs to simulated walking. Tune stiffness/damping if sim doesn't match real servo behavior. Add IMU noise if needed.
5. **Review legacy deployment scripts** — Audit `deployment/test_*.py` and `deployment/debug_*` scripts. Migrate to 48D/raw-observation path or retire stale 50D/phase-based scripts.

## LOW PRIORITY — Investigation

6. **Debug DirectRLEnv standing trap** — The direct-env architecture doesn't walk despite fixing action clamping and joint penalty scope. Root cause unknown. Lower priority since manager-based works.

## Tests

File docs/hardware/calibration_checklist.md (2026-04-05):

# Harold Servo Calibration Checklist

Follow these steps *with the robot safely supported* before running the exported policy. You will need the existing Arduino sketches under `firmware/CalibrationAndSetup/`. Record all offsets and settings in your engineering log when you finish.

## 0. Prep
- **Power**: bench supply or fully charged pack. Keep an inline fuse/E-stop available.
- **Support**: suspend Harold so the legs can move freely without ground contact.
- **Connections**: ESP32 USB to host laptop, servo bus power on, verify polarity.
- **Tooling**: Arduino IDE / `arduino-cli` configured for your ESP32 board, SCServo library installed.

## 1. Bus Sanity Check (`Ping/` sketch)
1. Open `firmware/CalibrationAndSetup/Ping/Ping.ino`.
2. Flash to the ESP32, open Serial Monitor @115200 baud.
3. Confirm IDs 1–12 respond. If any are missing, diagnose wiring/ID before proceeding.
4. Log any non-responding servo IDs.

## 2. Midpoint Trim (`CalibrateMiddles/CalibrateMiddles.ino`)
1. Flash the calibrator sketch.
2. For each servo ID 1→12:
   - Use `a/d` (±100) and `s/w` (±10) commands to align the joint mechanically to its neutral position (leg vertical, knee neutral).
   - Press `p` to save the offset; the sketch recenters automatically.
   - Record the saved offset value (printout) in your log.
3. After all joints, the sketch reports completion. Power-cycle the servo bus to ensure trims are stored.

## 3. Motion Sweep (`ChainMovementTest/ChainMovementTest.ino`)
1. Flash the chain movement test.
2. Observe each joint executing centre → +45° → centre → –45° → centre.
3. Verify direction signs match expectations (e.g., positive shoulder angle abducts the leg).
   Positive shoulder commands should mean the same body-relative motion on both left and right legs; if a right shoulder is reversed, fix the low-level servo `DIR`/`direction` mapping, not the high-level shoulder sign convention.
4. Note any joints that stall, jitter, or hit mechanical stops before ±45°.

## 4. Radian Command Gate (`SinglePositionTest/SinglePositionTest.ino`)
1. Flash the single-position test sketch.
2. With Serial Monitor open, send the ready-stance command from `deployment/config/stance.yaml`.
   Copy the current joint targets from the YAML so the stance stays in sync.
   The robot should settle into the nominal stance without visible lean.
3. Test a few additional targets (e.g., +0.2 rad on `fl_thigh`, –0.2 rad on `fr_thigh`) and verify motion directions.
   Include a shoulder sanity check on both sides so you confirm the left/right shoulders share the same high-level sign semantics.
4. Confirm the sketch reports any clamping; repeated clamp messages mean trims or limits need adjustment.

## 5. Torque / Current Limits (optional but recommended)
- While running Step 4, note the reported load/current in Serial Monitor (if firmware prints them) or query parameters using the SCServo PC tool.
- Ensure torque limit registers (`SMS_STS_TORQUE_LIMIT_L`) remain near the factory value. Adjust only if you have a reason to derate.

## 6. Document Final Defaults
Record the following for later use in runtime software:
- Final offset counts saved per servo (from Step 2).
- Any servos with reversed directions compared to expectation (should all match `DIR` array now).
- Observed resting pose alignment (body level? any sag?).
- Maximum safe range observed for thighs/calves before mechanical interference.

## When Finished
- Re-flash the ESP32 with `firmware/StreamingControl/HaroldStreamingControl` after calibration.
- Keep this calibration log accessible; the host runtime will assume these trims when converting policy outputs to servo targets.

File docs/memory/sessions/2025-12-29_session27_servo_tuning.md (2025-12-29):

# Session 27: Servo Tuning & Hardware Diagnostics

**Date**: 2025-12-29
**Duration**: ~2 hours
**Platform**: Raspberry Pi 5 (2GB RAM)

## Summary

This session focused on diagnosing servo performance issues, validating the Pi 5 power supply, and understanding hardware limitations for sim-to-real transfer.

## Pi 5 Stress Test Results

Ran comprehensive stress tests to validate onboard power supply:

| Test | Duration | Peak Temp | Throttling | Status |
|---|---|---|---|---|
| CPU-only (4 cores) | 30s | 71.4°C | 0x0 | PASS |
| CPU+Memory+I/O | 30s | 75.2°C | 0x0 | PASS |
| Robot Controller Sim | 30s | 60.9°C | 0x0 | PASS |

**Conclusion**: Power supply is healthy. No undervoltage detected under any load.

## Servo Dead Zone Investigation

### Initial Diagnosis
- **Symptom**: Can rotate servo a bit before it "locks up and fights back"
- Dead zone registers (26-27) were already at minimum value (1 step = 0.088°)
- This is NOT a software dead zone issue

### Root Cause: Gear Backlash
The "dead zone" is actually **mechanical gear backlash** in the ST3215 servo gearbox:
- Servos have fine positioning capability when commanded
- But there's mechanical play (~1-3°) in the gear train
- Within this play zone, the servo doesn't resist movement
- Beyond the play zone, full servo resistance kicks in

### P Coefficient Experiments
Discovered undocumented register 21 (P coefficient) controls servo stiffness:

| P Value | Result |
|---|---|
| 32 (factory) | Normal response, noticeable play |
| 100 | Slightly stiffer |
| 200 | **Rapid oscillations** - unstable! |

**Conclusion**: Increasing P without matching D (damping) causes instability. Reverted to factory P=32.

### Key Finding
The gear backlash is a **hardware limitation** that cannot be fixed in software. The correct approach is to **model it in simulation** so the RL policy learns to be robust to it.

## Artifacts Created/Updated

### ServoTuning.ino (Enhanced)
`firmware/CalibrationAndSetup/ServoTuning/ServoTuning.ino`

New commands added:
- `x <id> <reg>` - Read raw register value
- `X <id>` - Dump all registers (0-70) for servo
- `W <id> <reg> <val>` - Write raw register value

### Full Register Dump (Servo 1)
```
00:   3   9   0   9   3   1   0   0   1   0
10:   0 255  15  70  80  40 232   3  12  44
20:  47  32  32   0  16   0   1   1 244   1
30:   1 183  15   0  20 200  80  10 200 200
40:   1  50 255   7   0   0 220   5 232   3
50:   0   0   0   0   0   1   1   8   0   0
60:  24   0 121  32   0   1   0 255   7   1
70:   0
```

Key undocumented registers:
- **Reg 21**: P coefficient (factory=32)
- **Reg 22**: D coefficient (factory=32)
- **Reg 23**: I coefficient (factory=0)
- **Reg 24**: Punch/min PWM (factory=16)

## Committed Changes

```
1a01974 Add collision-safe limits, 100% torque, and servo tuning utility
```

Changes included:
- `TORQUE_LIMIT = 1000` (100% max torque)
- `initServoTorque()` function
- Asymmetric collision-safe joint limits
- Watchdog timeout 250ms
- ServoTuning.ino utility with raw register access

## Critical Next Step: Model Backlash in Simulation

**Priority experiment for overnight run on desktop:**

The gear backlash creates a "friction-free zone" where small position errors don't generate corrective torque. To model this in Isaac Lab:

### Approach Options

1. **Observation noise** (simplest)
   - Increase joint position noise from 0.005 rad to 0.02-0.05 rad
   - Policy learns to handle position uncertainty

2. **Action noise**
   - Add noise to commanded positions
   - Simulates imprecise positioning

3. **Lower stiffness**
   - Reduce actuator stiffness to make servo "softer"
   - Not physically accurate but has similar effect

4. **Custom backlash model** (most accurate)
   - Implement position hysteresis in environment
   - Small errors don't generate torque until threshold exceeded

### Recommended Experiment

Start with increased observation noise (option 1) as it's simplest and already implemented:

```python
# In harold_isaac_lab_env_cfg.py - DomainRandomizationCfg
joint_position_noise: GaussianNoiseCfg = GaussianNoiseCfg(
    mean=0.0,
    std=0.03,  # Increased from 0.005 to ~1.7° to match backlash
)
```

Enable domain randomization after establishing baseline walking.

## Hardware Constraints Summary

| Parameter | Value | Notes |
|---|---|---|
| Gear backlash | ~1-3° | Mechanical, unfixable |
| Dead zone registers | 1 (minimum) | Already optimized |
| P coefficient | 32 (factory) | Higher causes oscillation |
| D coefficient | 32 (factory) | Needs to match P |
| Torque limit | 1000 (100%) | Set at boot |

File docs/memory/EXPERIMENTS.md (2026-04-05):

# Harold Experiment Log

## Format
Each experiment entry contains:
- **Date**: When the experiment was run
- **ID**: Unique identifier (log directory name)
- **Config**: Key configuration changes from baseline
- **Duration**: Training duration/steps
- **Result**: Summary of outcomes
- **Metrics**: Key performance metrics
- **Notes**: Observations and insights

---

## Experiments

### MAINT-2026-03-16: Export Metadata Fallback + Status Termination Tags
- **Date**: 2026-03-16
- **ID**: manifestless/non-flat export metadata fix, termination tag lookup fix
- **Config**:
  - Exporter now resolves action scale and joint limits from `manifest.json`, then `params/env.yaml`, before using task defaults
  - `harold status` aux termination metrics now read the real `Info / Episode_Termination/*` tags and tolerate `Episode_Metric/termination_*` fallbacks
  - Added regression tests for manifestless export metadata and termination metric lookup
- **Duration**: single maintenance pass
- **Result**: **PASS** - manifestless rough/non-flat checkpoints now export correct metadata and status diagnostics surface termination counters again
- **Metrics**:
  - `~/Desktop/env_isaaclab/bin/python -m pytest deployment/tests/test_export_policy.py deployment/tests/test_harold_cli.py deployment/tests/test_inference.py -q`: 14 passed
  - `~/Desktop/env_isaaclab/bin/python -m py_compile common/policy_config.py policy/export_policy.py scripts/harold.py deployment/tests/test_export_policy.py deployment/tests/test_harold_cli.py`
- **Notes**:
  - Isaac Lab `params/env.yaml` snapshots use `!!python/tuple`, so `yaml.safe_load` is insufficient; `yaml.full_load` works for these local generated files.
  - Verified against real runs that `resolve_export_training_config()` returns `action_scale=1.0` plus mechanical joint bounds for `terrain_58` and `2026-03-15_02-03-30_ppo_torch`.
  - Verified against `2026-03-15_02-10-19_ppo_torch` that termination counters now resolve through `harold.get_metrics()`.

### MAINT-2026-03-15: Deployment Sign Convention Alignment + Train Guard
- **Date**: 2026-03-15
- **ID**: deployment sign-source unification, metadata/hardware mismatch guard, `harold train` relaunch guard
- **Config**:
  - Moved deployment sign resolution onto the hardware-backed convention in `deployment/config/hardware.yaml`
  - Updated observation/action conversion to share the same sign resolver and reject mismatched export metadata
  - Restored non-destructive `harold train` behavior when a tracked run or orphan processes already exist
- **Duration**: single maintenance pass
- **Result**: **PASS** - deployment no longer splits observation vs command shoulder semantics, and CLI relaunch no longer tears down active work
- **Metrics**:
  - `python3 -m py_compile common/policy_config.py deployment/inference/action_converter.py deployment/inference/observation_builder.py deployment/inference/harold_controller.py scripts/harold.py deployment/tests/test_inference.py deployment/tests/test_harold_cli.py`
  - `pytest deployment/tests/test_inference.py deployment/tests/test_harold_cli.py -q`: 11 passed
- **Notes**:
  - The stale mirrored-shoulder config was in `deployment/config/cpg.yaml`; the Pi runtime, calibration sketch, standalone gait firmware, and streaming firmware all already treated shoulders as non-mirrored semantic joints.
  - Export metadata with shoulder signs `[1, 1, 1, 1]` matched the real hardware path; the fix was to unify deployment around that convention rather than reintroduce mirrored shoulders in metadata.

### SECURITY-2026-03-15: Public Repo Wi-Fi Secret Remediation
- **Date**: 2026-03-15
- **ID**: tracked root-level `.nmconnection` history scrub on `main` and `autoresearch/session-2026-03-14`
- **Config**:
  - Removed the tracked NetworkManager profile from git history with `git filter-repo --path <profile>.nmconnection --invert-paths`
  - Rewrote historical SSID mentions with `git filter-repo --replace-text`
  - Force-pushed rewritten `main` and `autoresearch/session-2026-03-14` with explicit lease checks
- **Duration**: single maintenance pass
- **Result**: **PASS** - public branch history no longer contains the tracked `.nmconnection` file or its Wi-Fi identifiers
- **Notes**:
  - The local `.nmconnection` file was left on disk as an ignored, untracked file so machine networking is not disrupted.
  - A pre-rewrite bundle and working-tree patch were saved under `/tmp/harold-secret-cleanup.1ooni1/` during the remediation.

### AUDIT-EXPORT-2026-03-15: 48D Export And Validation
- **Date**: 2026-03-15
- **ID**: `deployment/policy/harold_policy.onnx`, `deployment/policy/harold_policy.ts`, `deployment/policy/policy_metadata.json`
- **Config**:
  - Exported from `logs/skrl/harold_direct/terrain_64_2/checkpoints/best_agent.pt`
  - Metadata derived from checkpoint normalization stats and canonical stance/config
  - Desktop venv updated with `deployment/requirements.txt` so ONNX-side validation could run locally
- **Duration**: single export plus validation pass
- **Result**: **PASS** - export/deployment path now agrees on 48D
- **Metrics**:
  - `policy/validate_export.py`: ONNX vs reference `mean.max_abs=2.15e-06`
  - `deployment/validation/validate_onnx_quick.py`: PASS
  - `deployment/validation/validate_onnx_vs_sim.py --data deployment/validation/sim_episode.json`: PASS (20/20 timesteps)
- **Notes**:
  - Controller initialization now accepts regenerated 48D metadata and reaches the hardware-connect boundary without legacy-dimension failure.

### EXP-257: Audit Phase 1 Flat Smoke
- **Date**: 2026-03-15
- **ID**: `2026-03-15_02-00-25_ppo_torch`
- **Config**:
  - Flat task, RL mode
  - `python scripts/harold.py train --duration fast --num-envs 64`
  - `HAROLD_POLICY_LOG_DIR=tmp/audit_phase1_policy_log_64d`
- **Duration**: ~90s before manual stop
- **Result**: **SMOKE PASS** - launcher, mandatory video, status reporting, and multi-env policy logging all worked
- **Metrics**:
  - `harold status`: running at ~12.9 avg it/s with 64 envs
  - `harold validate EXP-257`: STANDING (`episode_length=599`, `upright_mean=0.9885`, `height_reward=0.9237`, `vx_w_mean=-0.0082`)
- **Notes**:
  - Video files written under `logs/skrl/harold_direct/2026-03-15_02-00-25_ppo_torch/videos/train/`
  - Policy log smoke produced `tmp/audit_phase1_policy_log_64d/policy_steps.jsonl` with 504 entries
  - Flat termination telemetry buckets were verified separately in `2026-03-15_02-10-19_ppo_torch` after the tensor-scalar logging fix.

### EXP-259: Audit Phase 2 Rough Smoke
- **Date**: 2026-03-15
- **ID**: `2026-03-15_02-03-30_ppo_torch`
- **Config**:
  - Rough task, RL mode
  - `python scripts/harold.py train --task rough --duration fast --num-envs 64`
- **Duration**: ~78s before manual stop
- **Result**: **SMOKE PASS** for launcher/video/randomization telemetry, **TASK FAIL** on current policy state
- **Metrics**:
  - `harold status`: SANITY_FAIL (`episode_length≈5`, `height_reward≈0.13`)
  - TensorBoard emitted `terrain_level_{min,mean,max}` and `randomized_{friction,stiffness,damping,mass_scale}_mean`
- **Notes**:
  - Video fallback for non-flat tasks produced `rl-video-step-0-main.mp4`
  - Rough reset path now starts cleanly with actual property mutation and terrain-span logging enabled.

### HW-CPG-2026-01-04: Baseline Comparison (Test 1-3)
- **Date**: 2026-01-04
- **ID**: `session_2026-01-04_18-40-39.csv`, `session_2026-01-04_18-41-11.csv`, `session_2026-01-04_18-43-41.csv`
- **Config**:
  - Test 1: `frequency_hz=0.5`, `duty_cycle=0.6` (CPG-only)
  - Test 2: `frequency_hz=0.4`, `duty_cycle=0.5`, `stride_scale=0.35`, `calf_lift_scale=0.85`, rear boost
  - Test 3: Test 2 on lower-friction surface
- **Duration**: 3 × 10s CPG-only runs
- **Result**: **Test 3 best** (selected as baseline for sim-to-real alignment)
- **Notes**:
  - Logs on Pi: `/home/pi/harold/deployment/sessions/`
  - Local copies: `logs/hardware_sessions/`

### HW-CPG-2026-01-04: Rear-Leg Lift Tuning (RPi)
- **Date**: 2026-01-04
- **ID**: `session_2026-01-04_01-21-09.csv`, `session_2026-01-04_01-23-06.csv`, `session_2026-01-04_01-51-05.csv`, `session_2026-01-04_02-32-11.csv`, `session_2026-01-04_05-44-24.csv`
- **Config**:
  - duty-cycle gait (stance/swing split)
  - `frequency_hz=0.4`, `duty_cycle=0.5`
  - `stride_scale=0.35`, `calf_lift_scale=0.85`
  - per-leg scales: `stride_scale_front=1.0`, `stride_scale_back=1.3`, `calf_lift_scale_front=1.0`, `calf_lift_scale_back=1.15`
- **Duration**: multiple 10s CPG-only runs
- **Result**: IMPROVED - smoother gait, reduced impact; rear legs still skimming (no clear air time)
- **Notes**:
  - ESP32 handshake failed after calibration firmware; reflash StreamingControl fixed it.
  - Keep `harold` service stopped during manual tests to avoid auto-walking.

### SIM-CPG-2026-01-04: Command Alignment + Actuator Sweep
- **Date**: 2026-01-04
- **ID**: `deployment/validation/sim_logs/sim_cpg_test3.csv`, `deployment/validation/sim_logs/actuator_sweep_results.csv`
- **Config**:
  - CPG baseline from `deployment/config/cpg.yaml` (Test 3).
  - Sim CPG leg trajectory updated to match hardware generator math (stride/lift scaling ignored).
  - Actuator sweep (stiffness/damping) against hardware log `session_2026-01-04_18-43-41.csv`.
- **Duration**: 10s sim log @ 5 Hz, multi-run sweep.
- **Result**: **Aligned** command generation (sim cmd_pos matches hardware generator at logged phase).
- **Metrics**:
  - Best tracking match (effort=2.8): stiffness=1200, damping=75 (cost_all≈0.0044).
- **Notes**:
  - Shared CPG kernel lives in `common/cpg_math.py` to prevent sim/hardware drift.

### EXP-001: Simulation Boot Test
- **Date**: 2025-12-19
- **ID**: `2025-12-19_23-03-04_ppo_torch`
- **Config**: Default flat terrain, 1 env, 1 iteration (24 timesteps)
- **Duration**: 14 seconds total (2 seconds training)
- **Result**: SUCCESS - Simulation boots and runs correctly
- **Metrics**:
  - Scene creation: 0.22s
  - Simulation start: 0.61s
  - Training throughput: ~12 it/s
- **Notes**: Headless mode works. Logging infrastructure intact. Ready for full experiments.

---

### EXP-002: Policy Evaluation (terrain_62)
- **Date**: 2025-12-19
- **ID**: `terrain_62/videos/play/rl-video-step-0.mp4`
- **Config**: Best checkpoint (agent_128000.pt), 1 env, 500 steps
- **Duration**: 25 seconds simulation time
- **Result**: FAILURE - Robot stands in place, zero forward locomotion
- **Metrics**:
  - Forward displacement: 0 meters
  - Standing stability: Excellent (no falls)
  - Episode completion: 100% (no early terminations)
- **Notes**:
  - Policy learned to stand stably but not walk
  - Training videos confirm all 4096 robots remain at spawn positions
  - Reward structure allows "standing" as optimal strategy
- **Next Steps**: Modify reward weights to incentivize forward motion

---

### EXP-003: Walking Gait Experiment - FAILED
- **Date**: 2025-12-19/20
- **ID**: `2025-12-19_23-35-57_ppo_torch`
- **Config Changes**:
  - `progress_forward_pos`: 80 → 150 (increased forward reward)
  - `rear_support_bonus`: 0.6 → 0.0 (removed standing incentive)
  - Added `standing_penalty`: 2.0 (penalizes velocity < 0.05 m/s)
- **Duration**: ~38,000 timesteps before manual stop (~16% of planned)
- **Status**: FAILED
- **Result**: Robot falls over and stays on ground
- **Close-up Observation** (single robot eval):
  - Step 10: Robot in low crouch
  - Step 75: Robot has FALLEN flat on ground
  - Step 150-290: Robot remains prone, never recovers
- **Analysis**:
  - Standing penalty broke stable standing behavior
  - Robot attempts to move to avoid penalty but lacks coordination
  - Falls over and cannot recover
  - Essentially learned "fall and flop" instead of "walk"
- **Lesson**: Cannot just penalize standing - need to maintain balance while incentivizing movement

---

### EXP-004: Balanced Forward Incentive - FAILED
- **Date**: 2025-12-20
- **ID**: `2025-12-20_00-17-40_ppo_torch`
- **Config Changes** (from EXP-003):
  - `standing_penalty`: 2.0 → 0.0 (REMOVED)
  - `upright_reward`: 1.8 → 5.0 (INCREASED)
  - `progress_forward_pos`: 150 → 100 (MODERATED)
- **Duration**: ~12,000 timesteps before manual stop
- **Status**: FAILED
- **Result**: Robot falls and stays on ground (same as EXP-003)
- **Observations**:
  - Step 2000: Robot standing (promising!)
  - Step 6000: Robot fallen
  - Step 12000: Robot still fallen - converged to prone position
- **Analysis**:
  - upright_reward=5.0 still not enough to prevent falling
  - Training from scratch takes too long to learn balance
  - Forward reward still incentivizes motion before robot learns to balance
- **Lesson**: Need to either (a) start from checkpoint that can stand, or (b) dramatically increase upright reward

---

### EXP-005: Fine-tune from terrain_62 - INCONCLUSIVE
- **Date**: 2025-12-20
- **ID**: `2025-12-20_00-32-14_ppo_torch`
- **Config**: Same rewards as EXP-004, but starting FROM terrain_62 checkpoint
- **Duration**: ~4000 timesteps before manual stop
- **Status**: INCONCLUSIVE - Shows oscillation between standing and falling
- **Observations**:
  - Step 2000: Robot falling (pre-trained standing behavior degrading)
  - Step 4000: Robot oscillating - some frames show standing attempts, then falling
- **Analysis**:
  - Even with pre-trained checkpoint, reward gradients push policy toward instability
  - The forward reward creates gradient that disrupts standing equilibrium
  - Robot attempts to stand but can't maintain balance while attempting forward motion
- **Key Insight**: Forward reward modulated by upright isn't enough - the gradient still destabilizes

---

### EXP-006: High Upright Reward - FAILED
- **Date**: 2025-12-20
- **ID**: `2025-12-20_00-44-38_ppo_torch`
- **Config Changes**:
  - `upright_reward`: 5.0 → 15.0 (3x increase to anchor stability)
  - All else unchanged from EXP-004
- **Duration**: ~12,000 timesteps before manual stop
- **Status**: FAILED
- **Result**: Robot falls by step 4000 and stays fallen through step 12000
- **Observations**:
  - Step 4000: Robot already fallen, lying on side
  - Step 8000: Robot still fallen, no recovery
  - Step 12000: Robot prone on ground, no improvement
- **Analysis**:
  - High upright reward (15.0) still insufficient to prevent falling
  - The reward structure alone cannot prevent initial instability
  - Once fallen, robot has no incentive to get up (no termination)
- **Key Insight**: Need to PREVENT falling behaviors from being learned, not just reward uprightness

---

## Session 2 Summary (2025-12-20 Overnight)

### Experiments Run
| ID | Approach | Result |
|----|---|---|
| EXP-006 | High upright reward (15.0) | FAILED - Robot still falls |
| EXP-007 | Aggressive termination (-0.7) | FAILED - Makes learning harder |
| EXP-008 | Fine-tune terrain_62 + low forward (30) | FAILED - Stability degraded |
| EXP-009 | Gait rewards + very low forward (10) | FAILED - Same pattern |
| EXP-010 | Stability-only (zero forward) | PARTIAL - Standing at 5k-10k, fell by 15k |
| EXP-011 | Stability + aggressive termination | FAILED - Made learning harder |
| EXP-012 | Stability + frequent checkpoints | **SUCCESS** - Stable standing, saved agent_5000.pt |
| EXP-013 | Fine-tune agent_5000 + forward=3.0 | FAILED - Destabilized immediately |
| EXP-014 | Fine-tune agent_5000 + leg movement only | FAILED - Still destabilized |

### KEY FINDING: The Standing Equilibrium is Extremely Fragile
Every attempt to add ANY motion reward (forward velocity OR gait/leg movement)
eventually destabilizes the standing behavior. The pattern is consistent:
- Step 2500-5000: Standing maintained
- Step 5000-7500: Degradation begins
- Step 7500+: Robot fallen

### EXP-012: Stability + Frequent Checkpoints - **PARTIAL SUCCESS**
- **Date**: 2025-12-20
- **ID**: `2025-12-20_02-18-43_ppo_torch`
- **Config**: upright=25, height=8, forward=0, termination=-0.5
- **Status**: **ACHIEVED STABLE STANDING**
- **Saved Checkpoint**: `agent_5000.pt` shows clear standing posture
- **Observations**:
  - Step 2500: Standing ✓
  - Step 5000: Standing ✓ (BEST CHECKPOINT)
  - Step 7500: Mixed (some fallen frames)
  - Step 10000: Standing ✓
- **Key**: This proves stable standing CAN be learned from scratch

### EXP-013: Fine-tune with Minimal Forward - FAILED
- **Date**: 2025-12-20
- **ID**: `2025-12-20_02-30-55_ppo_torch`
- **Config**: Used agent_5000.pt, forward=3.0, upright=25
- **Status**: FAILED
- **Observations**: Standing at step 0, fallen by step 5000
- **Analysis**: Even forward_reward=3.0 is too destabilizing

### EXP-014: Leg Movement Only - FAILED
- **Date**: 2025-12-20
- **ID**: `2025-12-20_02-40-39_ppo_torch`
- **Config**: forward=0, leg_movement=2.0, feet_air_time=1.0
- **Status**: FAILED
- **Observations**: Standing at 2500, fallen by 5000
- **Analysis**: Gait rewards ALSO destabilize standing

### EXP-009: Gait Rewards - FAILED
- **Date**: 2025-12-20
- **ID**: `2025-12-20_01-30-34_ppo_torch`
- **Config Changes**:
  - `progress_forward_pos`: 30 → 10 (even lower)
  - Added gait rewards: feet_air_time=2.0, diagonal_gait=3.0, leg_movement=1.5
  - Started from terrain_62 checkpoint
- **Duration**: ~12,000 timesteps before stop
- **Status**: FAILED
- **Result**: Same degradation as EXP-008
- **Observations**:
  - Step 4000: Low crouch
  - Step 8000: Fallen
  - Step 12000: Still fallen
- **Analysis**: Gait rewards don't prevent falling. terrain_62 optimized for standing still.

### Critical Pattern Identified
ALL experiments (006-009) follow identical failure:
- Step 4000: Low crouch (initial terrain_62 stability)
- Step 8000+: Robot fallen
- Root cause: terrain_62 optimized for standing still, any motion reward disrupts equilibrium

### EXP-008: Fine-tune from terrain_62 - FAILED
- **Date**: 2025-12-20
- **ID**: `2025-12-20_01-14-41_ppo_torch`
- **Config Changes**:
  - Started from `terrain_62/checkpoints/agent_128000.pt`
  - `progress_forward_pos`: 100 → 30 (much lower)
  - `upright_reward`: 15 → 20 (very high)
  - Kept termination at -0.7
- **Duration**: ~12,000 timesteps before manual stop
- **Status**: FAILED
- **Result**: Initial stability degraded over training
- **Observations**:
  - Step 4000: Robot in LOW CROUCH (promising! not fully fallen)
  - Step 8000: Robot fallen
  - Step 12000: Robot still fallen
- **Analysis**:
  - Pre-training provided initial stability (step 4000 was best result yet!)
  - But forward reward gradient still eventually destabilizes
  - Even forward_reward=30 is too destabilizing
- **Key Insight**: Velocity rewards fundamentally destabilize - need gait-based rewards instead

### EXP-007: Aggressive Termination - FAILED
- **Date**: 2025-12-20
- **ID**: `2025-12-20_00-59-47_ppo_torch`
- **Config Changes**:
  - `orientation_threshold`: -0.5 → -0.7 (terminate earlier when tilting)
  - `upright_reward`: 15.0 (unchanged from EXP-006)
- **Duration**: ~12,000 timesteps before manual stop
- **Status**: FAILED
- **Result**: Robot still falls immediately after reset
- **Observations**:
  - Step 4000: Robot fallen/low in all frames
  - Step 8000: Same behavior
  - Step 12000: No improvement
- **Analysis**:
  - Aggressive termination ends episodes quickly but doesn't help learning
  - Robot doesn't have initial policy to stay upright
  - Training from scratch can't learn to stand AND walk simultaneously
- **Key Insight**: Need to fine-tune from terrain_62 checkpoint (already knows how to stand)

---

## Session 1 Summary (2025-12-19/20)

### Experiments Run
| ID | Approach | Result |
|----|---|---|
| EXP-001 | Simulation boot test | SUCCESS |
| EXP-002 | Evaluate terrain_62 | Robot stands, doesn't walk |
| EXP-003 | Add standing penalty | FAILED - Robot falls immediately |
| EXP-004 | Remove penalty, increase upright | FAILED - Robot still falls |
| EXP-005 | Fine-tune from checkpoint | INCONCLUSIVE - Oscillates |

### Key Learnings
1. terrain_62 learned stable STANDING, not walking
2. Standing penalty is too aggressive - breaks balance immediately
3. upright_reward=5.0 is insufficient to maintain balance with forward_reward=100
4. Even fine-tuning from stable checkpoint, forward reward disrupts balance
5. The robot can't simultaneously learn to balance AND move forward

### Recommended Next Approaches
1. **MUCH higher upright reward** (15-20) to strongly anchor stability
2. **Episode termination on fall** so robot can't learn "fallen" behaviors
3. **Explicit gait rewards** for leg alternation (don't just reward velocity)
4. **Curriculum**: First achieve stable walking-in-place, then add forward bias

---

## Historical Experiments (Pre-Memory System)
Reference logs in `logs/skrl/harold_direct/`:
- `terrain_57` through `terrain_64_2`: Major training runs (Sep 2025)
- `2025-10-*`: Recent shorter experiments (Oct 2025)
- Best performing: `terrain_62` (524M+ steps, exported for deployment)

---

## Session 3 (2025-12-20 Morning)

### EXP-015: Extended Stability Training - COMPLETED
- **Date**: 2025-12-20
- **ID**: `2025-12-20_09-28-17_ppo_torch`
- **Hypothesis**: Longer stability-only training produces more robust standing that may resist destabilization
- **Config**:
  - `upright_reward`: 25.0
  - `height_reward`: 8.0
  - `forward_reward`: 0.0 (ZERO)
  - `gait_rewards`: 0.0 (ALL ZERO)
  - `termination`: -0.5 (standard)
  - `checkpoint_interval`: 5000
  - `timesteps`: 30000
- **Duration**: ~25 min at 20-24 it/s
- **Status**: **COMPLETED**
- **Visualization Fix**: Added `origin_type="env"` to ViewerCfg to show single robot

#### Checkpoints Saved:
| Step | File | Size |
|---|---|---|
| 5000 | agent_5000.pt | 2.2MB |
| 10000 | agent_10000.pt | 2.2MB |
| 15000 | agent_15000.pt | 2.2MB |
| 20000 | agent_20000.pt | 2.2MB |
| 25000 | agent_25000.pt | 2.2MB |
| 30000 | agent_30000.pt | 2.2MB |
| best | best_agent.pt | 2.9MB |

#### Videos Recorded:
- Training videos at steps 0, 5000, 10000, 15000, 20000, 25000 (~17KB each, 15sec)
- Play evaluation video: 500 steps (25sec, 1.7MB)

#### Path to Best Checkpoint:
`/home/matteo/Desktop/code_projects/harold/logs/skrl/harold_direct/2025-12-20_09-28-17_ppo_torch/checkpoints/agent_30000.pt`

#### TensorBoard Analysis (Quantitative):
| Metric | Step 10 | Step 5000 | Step 30000 | Status |
|---|---|---|---|---|
| upright_mean | 0.10 | 0.89 | 0.88 | UNSTABLE |
| episode_length | 3.8 | 253 | 270 | Improving |
| total_reward | 88 | 6286 | 6700 | Improving |

**Final Status**: UNSTABLE (upright_mean=0.86-0.88, threshold for STABLE is 0.9)

**Key Findings**:
- Robot improved from immediate falling (upright=0.1) to partial stability (upright=0.87)
- Never reached STABLE_STANDING threshold (>0.9)
- Episode lengths increased from ~4 steps to ~180-270 steps (good progress)
- height_err_abs metric has a bug (shows impossible 300-600m values)
- Visualization fix (origin_type="env") caused white screen - **REVERTED**

#### Next Steps:
- Robot is UNSTABLE, not STABLE_STANDING - needs further optimization
- Consider higher upright_reward or different termination threshold
- May need longer training or curriculum approach

---

## Session 4 (2025-12-20 Afternoon) - OBSERVABILITY FAILURE

### CRITICAL: All EXP-017 through EXP-022 produced FALLEN robots!

**What I thought happened**: I saw `upright_mean > 0.9` and `vx_w_mean > 0.1` and concluded
the robot was walking.

**What actually happened**: Video review showed the robot **fell forward onto its elbows**
after spawning. The back legs squatted to keep the rear elevated.

**Why metrics were misleading**:
- `upright_mean = 0.93`: Back end elevated = high upright (even though fallen!)
- `vx_w_mean = 0.1+`: Falling forward = positive velocity
- `height_reward = 0.32`: **SHOULD BE ~3.0** for proper standing
- `body_contact_penalty = -0.34`: **Body was touching ground**
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

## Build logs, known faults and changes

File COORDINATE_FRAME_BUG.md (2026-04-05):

# Harold Coordinate Frame Investigation

## Status: RESOLVED — No Bug Found

Investigation on 2026-03-18/19 determined that the original identity quaternion setup was correct. A 180° Z rotation was temporarily applied (EXP-429) based on incorrect analysis, then reverted after diagnostic testing proved the original setup was sound.

## Timeline

1. **Pre-EXP-429**: Robot trained with identity quaternion `(1,0,0,0)`. Performance appeared poor — robot seemed to walk backward in some video views.
2. **EXP-429**: 180° Z rotation applied based on URDF joint naming analysis (FL/FR at -X in URDF → assumed body +X pointed backward). Performance appeared to improve.
3. **2026-03-18 diagnostic**: Velocity push test (+2.0 m/s world +X) showed `vx_b = +vx_w` with identity quaternion — body +X *does* align with world +X. The URDF analysis was wrong because the USD file (converted from URDF) has FL/FR at +X, not -X.
4. **2026-03-19 reward diagnostic**: Logged `forward_motion` and `track_lin_vel_xy` rewards alongside velocity during the push test. Rewards correctly increase with positive body-frame velocity. No misalignment found.
5. **Resolution**: Reverted all quaternion rotations to identity. The performance difference attributed to the rotation was likely coincidental (other reward/config changes were made simultaneously).

## What Was Investigated

### USD Asset Inspection
Used `pxr.Usd` API from Isaac Sim packages to inspect `part_files/V4/harold_8.usd`:
- FL/FR joints are at +X in the USD (opposite from URDF convention)
- All `orient` values are identity — no hidden rotations baked in
- The URDF-to-USD conversion flipped the joint positions but this is consistent — body +X still aligns with visual forward

### Diagnostic Test Results
With identity quaternion, pushing env 0 at +2.0 m/s in world +X:
```
step=  1 | vx_w=+2.002 vx_b=+1.994 | cmd_vx=0.194 | fwd_reward=+9.966 track_reward=+0.000
step=  3 | vx_w=+1.533 vx_b=+1.530 | cmd_vx=0.194 | fwd_reward=+7.649 track_reward=+0.000
step= 24 | vx_w=+0.274 vx_b=+0.272 | cmd_vx=0.297 | fwd_reward=+1.360 track_reward=+3.590
```
- `vx_b ≈ vx_w` (identity quaternion, no yaw rotation)
- `forward_motion` reward is positive when vx_b is positive (correct)
- `track_lin_vel_xy` peaks when velocity matches command (correct)

## Key Facts

- **Isaac Lab uses (w, x, y, z) quaternion format.** Identity = `(1.0, 0.0, 0.0, 0.0)`.
- **Body-frame velocity** (`root_lin_vel_b`) is computed via `quat_apply_inverse(root_quat_w, root_lin_vel_w)`.
- **Commands are body-frame.** `cmd_vx` range: [0.0, 0.3] m/s. Both commands and rewards use body-frame velocity, making the reward system rotation-invariant.
- **With identity quaternion**: body +X = world +X = robot visual forward. Positive `vx_b` = moving forward = positive reward. Everything aligns.

## Files Changed During This Investigation

| File | Change |
|---|---|
| `harold_flat/harold.py` | Kept at identity quaternion `(1,0,0,0)`, cleaned up diagnostic comment |
| `harold_rough/harold.py` | Reverted from 180° Z rotation back to identity quaternion |
| `harold_flat/train_env.py` | Removed diagnostic velocity push and reward logging code |
| `deployment/inference/observation_builder.py` | Updated comment — no sign flip needed with identity quat |
| `common/multi_camera_video.py` | Fixed axis overlay gizmos to show robot-relative directions |

## Camera Axis Overlays

During this investigation, the camera axis overlay gizmos in `multi_camera_video.py` were corrected to show **robot-relative** directions (not camera-relative). The overlays now show where the robot's own +X (forward), +Y (left), and +Z (up) project onto each camera view.

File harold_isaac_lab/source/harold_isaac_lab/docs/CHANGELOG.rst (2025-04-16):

Changelog
---------

0.1.0 (2025-04-16)
~~~~~~~~~~~~~~~~~~

Added
^^^^^

* Created an initial template for building an extension or project based on Isaac Lab

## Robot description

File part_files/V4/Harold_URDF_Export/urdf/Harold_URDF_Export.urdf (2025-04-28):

<?xml version="1.0" encoding="utf-8"?>
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
<robot name="Harold_URDF_Export">
  <link name="Body">
    <inertial>
      <origin xyz="0.00050571 3.9206E-05 0.0065559" rpy="0 0 0" />
      <mass value="0.65516" />
      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
    </inertial>
    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
  </link>
  <link name="fl_shoulder">
    <inertial>
      <origin xyz="0.0226268804239232 0.0030897878880634 0.0167231448134229" rpy="0 0 0" />
      <mass value="0.0776965557993418" />
      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
    </inertial>
    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
  </link>
  <joint name="fl_shoulder_joint" type="revolute">
    <origin xyz="0.185 -0.0175 0.04805" rpy="1.5708 0 0" />
    <parent link="Body" />
    <child link="fl_shoulder" />
    <axis xyz="1 0 0" />
    <limit lower="0" upper="0" effort="0" velocity="0" />
  </joint>
  <link name="fl_thigh">
    <inertial>
      <origin xyz="-0.00156528908759812 0.0293750339010572 -0.0302869631953187" rpy="0 0 0" />
      <mass value="0.0916515025957822" />
      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
    </inertial>
    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
  </link>
  <joint name="fl_thigh_joint" type="revolute">
    <origin xyz="0.023 0.0101 0.011125" rpy="0 0 0" />
    <parent link="fl_shoulder" />
    <child link="fl_thigh" />
    <axis xyz="0 1 0" />
    <limit lower="0" upper="0" effort="0" velocity="0" />
  </joint>
  <link name="fl_calf">
    <inertial>
      <origin xyz="0.00237381613529569 0.022686943617349 -0.0344454986164686" rpy="0 0 0" />
      <mass value="0.0864459183664809" />
      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
    </inertial>
    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
  </link>
  <joint name="fl_calf_joint" type="revolute">
    <origin xyz="-0.0025 0.005 -0.10288" rpy="0 0 0" />
    <parent link="fl_thigh" />
    <child link="fl_calf" />
    <axis xyz="0 1 0" />
    <limit lower="0" upper="0" effort="0" velocity="0" />
  </joint>
  <link name="fr_shoulder">
    <inertial>
      <origin xyz="0.022652843501191 -0.00308978788806342 0.016723144813423" rpy="0 0 0" />
      <mass value="0.0776965557993418" />
      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
    </inertial>
    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
  </link>
  <joint name="fr_shoulder_joint" type="revolute">
    <origin xyz="0.185 -0.0175 -0.04795" rpy="1.5708 0 0" />
    <parent link="Body" />
    <child link="fr_shoulder" />
    <axis xyz="1 0 0" />
    <limit lower="0" upper="0" effort="0" velocity="0" />
  </joint>
  <link name="fr_thigh">
    <inertial>
      <origin xyz="-0.00156528908759815 -0.0293750339010572 -0.0302869631953187" rpy="0 0 0" />
      <mass value="0.0916515025957821" />
      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
    </inertial>
    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
  </link>
  <joint name="fr_thigh_joint" type="revolute">
    <origin xyz="0.0232 -0.0101 0.011125" rpy="0 0 0" />
    <parent link="fr_shoulder" />
    <child link="fr_thigh" />
    <axis xyz="0 1 0" />
    <limit lower="0" upper="0" effort="0" velocity="0" />
  </joint>
  <link name="fr_calf">
    <inertial>
      <origin xyz="0.00237381613529589 -0.0226869436158008 -0.0344454986164681" rpy="0 0 0" />
      <mass value="0.0864459183664809" />
      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
    </inertial>
    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
  </link>
  <joint name="fr_calf_joint" type="revolute">
    <origin xyz="-0.0025 -0.005 -0.10288" rpy="0 0 0" />
    <parent link="fr_thigh" />
    <child link="fr_calf" />
    <axis xyz="0 1 0" />
    <limit lower="0" upper="0" effort="0" velocity="0" />
  </joint>
  <link name="bl_shoulder">
    <inertial>
      <origin xyz="-0.0229731195760767 0.00308978788806345 0.016723144813423" rpy="0 0 0" />
      <mass value="0.0776965557993418" />
      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
    </inertial>
    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
  </link>
  <joint name="bl_shoulder_joint" type="revolute">
    <origin xyz="-0.1854 -0.0175 0.048" rpy="1.5708 0 0" />
    <parent link="Body" />
    <child link="bl_shoulder" />
    <axis xyz="1 0 0" />
    <limit lower="0" upper="0" effort="0" velocity="0" />
  </joint>
  <link name="bl_thigh">
    <inertial>
      <origin xyz="-0.0015652890875982 0.0293750339010572 -0.0302869631953187" rpy="0 0 0" />
      <mass value="0.0916515025957822" />
      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
    </inertial>
    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
  </link>
  <joint name="bl_thigh_joint" type="revolute">
    <origin xyz="-0.0226 0.0101 0.011125" rpy="0 0 0" />
    <parent link="bl_shoulder" />
    <child link="bl_thigh" />
    <axis xyz="0 1 0" />
    <limit lower="0" upper="0" effort="0" velocity="0" />
  </joint>
  <link name="bl_calf">
    <inertial>
      <origin xyz="0.00237381613529564 0.022686943617349 -0.0344454986164682" rpy="0 0 0" />
      <mass value="0.0864459183664809" />
      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
    </inertial>
    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
  </link>
  <joint name="bl_calf_joint" type="revolute">
    <origin xyz="-0.0025 0.005 -0.10288" rpy="0 0 0" />
    <parent link="bl_thigh" />
    <child link="bl_calf" />
    <axis xyz="0 1 0" />
    <limit lower="0" upper="0" effort="0" velocity="0" />
  </joint>
  <link name="br_shoulder">
    <inertial>
      <origin xyz="-0.022947156498809 -0.00308978788806343 0.016723144813423" rpy="0 0 0" />
      <mass value="0.0776965557993418" />
      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
    </inertial>
    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
  </link>
  <joint name="br_shoulder_joint" type="revolute">
    <origin xyz="-0.1854 -0.0175 -0.048" rpy="1.5708 0 0" />
    <parent link="Body" />
    <child link="br_shoulder" />
    <axis xyz="1 0 0" />
    <limit lower="0" upper="0" effort="0" velocity="0" />
  </joint>
  <link name="br_thigh">
    <inertial>
      <origin xyz="-0.00156528908759812 -0.0293750339010572 -0.0302869631953187" rpy="0 0 0" />
      <mass value="0.0916515025957821" />
      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
    </inertial>
    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
  </link>
  <joint name="br_thigh_joint" type="revolute">
    <origin xyz="-0.0224 -0.0101 0.011125" rpy="0 0 0" />
    <parent link="br_shoulder" />
    <child link="br_thigh" />
    <axis xyz="0 1 0" />
    <limit lower="0" upper="0" effort="0" velocity="0" />
  </joint>
  <link name="br_calf">
    <inertial>
      <origin xyz="0.00237381613529586 -0.0226869436158008 -0.0344454986164686" rpy="0 0 0" />
      <mass value="0.0864459183664809" />
      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
    </inertial>
    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
  </link>
  <joint name="br_calf_joint" type="revolute">
    <origin xyz="-0.0025 -0.005 -0.10288" rpy="0 0 0" />
    <parent link="br_thigh" />
    <child link="br_calf" />
    <axis xyz="0 1 0" />
    <limit lower="0" upper="0" effort="0" velocity="0" />
  </joint>
</robot>

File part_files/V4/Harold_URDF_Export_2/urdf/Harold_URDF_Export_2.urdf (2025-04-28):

<?xml version="1.0" encoding="utf-8"?>
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
<robot name="Harold_URDF_Export_2">
  <link name="Body">
    <inertial>
      <origin xyz="-0.000505711047275829 -3.92059868626698E-05 0.00655594728550839" rpy="0 0 0" />
      <mass value="0.655160642240757" />
      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
    </inertial>
    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
  </link>
  <link name="fl_shoulder">
    <inertial>
      <origin xyz="-0.0226268804239233 0.016723144813423 0.00308978788806343" rpy="0 0 0" />
      <mass value="0.0776965557993418" />
      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
    </inertial>
    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
  </link>
  <joint name="fl_shoulder_joint" type="revolute">
    <origin xyz="-0.185 -0.04805 0.0175" rpy="1.5708 0 0" />
    <parent link="Body" />
    <child link="fl_shoulder" />
    <axis xyz="1 0 0" />
    <limit lower="0" upper="0" effort="0" velocity="0" />
  </joint>
  <link name="fl_thigh">
    <inertial>
      <origin xyz="0.00156528908759818 -0.0302869631953187 0.0293750339010572" rpy="0 0 0" />
      <mass value="0.0916515025957821" />
      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
    </inertial>
    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
  </link>
  <joint name="fl_thigh_joint" type="revolute">
    <origin xyz="-0.023 0.011125 0.0101" rpy="0 0 0" />
    <parent link="fl_shoulder" />
    <child link="fl_thigh" />
    <axis xyz="0 0 1" />
    <limit lower="0" upper="0" effort="0" velocity="0" />
  </joint>
  <link name="fl_calf">
    <inertial>
      <origin xyz="-0.00237381613529589 -0.034445498616468 0.0226869436173489" rpy="0 0 0" />
      <mass value="0.0864459183664809" />
      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
    </inertial>
    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
  </link>
  <joint name="fl_calf_joint" type="revolute">
    <origin xyz="0.00249999999999997 -0.102875 0.00500000000000111" rpy="0 0 0" />
    <parent link="fl_thigh" />
    <child link="fl_calf" />
    <axis xyz="0 0 1" />
    <limit lower="0" upper="0" effort="0" velocity="0" />
  </joint>
  <link name="fr_shoulder">
    <inertial>
      <origin xyz="-0.022652843501191 0.016723144813423 -0.00308978788806342" rpy="0 0 0" />
      <mass value="0.0776965557993418" />
      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
    </inertial>
    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
  </link>
  <joint name="fr_shoulder_joint" type="revolute">
    <origin xyz="-0.185 0.04795 0.0175" rpy="1.5708 0 0" />
    <parent link="Body" />
    <child link="fr_shoulder" />
    <axis xyz="1 0 0" />
    <limit lower="0" upper="0" effort="0" velocity="0" />
  </joint>
  <link name="fr_thigh">
    <inertial>
      <origin xyz="0.00156528908759818 -0.0302869631953186 -0.0293750339010572" rpy="0 0 0" />
      <mass value="0.0916515025957821" />
      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
    </inertial>
    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
  </link>
  <joint name="fr_thigh_joint" type="revolute">
    <origin xyz="-0.0232000000000001 0.011125 -0.0100999999999999" rpy="0 0 0" />
    <parent link="fr_shoulder" />
    <child link="fr_thigh" />
    <axis xyz="0 0 1" />
    <limit lower="0" upper="0" effort="0" velocity="0" />
  </joint>
  <link name="fr_calf">
    <inertial>
      <origin xyz="-0.00237381613529575 -0.0344454986164687 -0.0226869436158008" rpy="0 0 0" />
      <mass value="0.0864459183664809" />
      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
    </inertial>
    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
  </link>
  <joint name="fr_calf_joint" type="revolute">
    <origin xyz="0.0025 -0.102875 -0.00500000000000027" rpy="0 0 0" />
    <parent link="fr_thigh" />
    <child link="fr_calf" />
    <axis xyz="0 0 1" />
    <limit lower="0" upper="0" effort="0" velocity="0" />
  </joint>
  <link name="bl_shoulder">
    <inertial>
      <origin xyz="0.0229731195760768 0.016723144813423 0.00308978788806344" rpy="0 0 0" />
      <mass value="0.0776965557993418" />
      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
    </inertial>
    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
  </link>
  <joint name="bl_shoulder_joint" type="revolute">
    <origin xyz="0.1854 -0.048 0.0175" rpy="1.5708 0 0" />
    <parent link="Body" />
    <child link="bl_shoulder" />
    <axis xyz="1 0 0" />
    <limit lower="0" upper="0" effort="0" velocity="0" />
  </joint>
  <link name="bl_thigh">
    <inertial>
      <origin xyz="0.00156528908759815 -0.0302869631953187 0.0293750339010572" rpy="0 0 0" />
      <mass value="0.0916515025957821" />
      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
    </inertial>
    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
  </link>
  <joint name="bl_thigh_joint" type="revolute">
    <origin xyz="0.0226 0.011125 0.0101" rpy="0 0 0" />
    <parent link="bl_shoulder" />
    <child link="bl_thigh" />
    <axis xyz="0 0 1" />
    <limit lower="0" upper="0" effort="0" velocity="0" />
  </joint>
  <link name="bl_calf">
    <inertial>
      <origin xyz="-0.00237381613529594 -0.0344454986164687 0.0226869436173489" rpy="0 0 0" />
      <mass value="0.086445918366481" />
      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
    </inertial>
    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
  </link>
  <joint name="bl_calf_joint" type="revolute">
    <origin xyz="0.00249999999999997 -0.102875 0.00500000000000127" rpy="0 0 0" />
    <parent link="bl_thigh" />
    <child link="bl_calf" />
    <axis xyz="0 0 1" />
    <limit lower="0" upper="0" effort="0" velocity="0" />
  </joint>
  <link name="br_shoulder">
    <inertial>
      <origin xyz="0.0229471564988091 0.016723144813423 -0.00308978788806342" rpy="0 0 0" />
      <mass value="0.0776965557993418" />
      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
    </inertial>
    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
  </link>
  <joint name="br_shoulder_joint" type="revolute">
    <origin xyz="0.185399999999999 0.048 0.0175" rpy="1.5707963267949 0 0" />
    <parent link="Body" />
    <child link="br_shoulder" />
    <axis xyz="1 0 0" />
    <limit lower="0" upper="0" effort="0" velocity="0" />
  </joint>
  <link name="br_thigh">
    <inertial>
      <origin xyz="0.00156528908759818 -0.0302869631953186 -0.0293750339010572" rpy="0 0 0" />
      <mass value="0.0916515025957821" />
      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
    </inertial>
    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
  </link>
  <joint name="br_thigh_joint" type="revolute">
    <origin xyz="0.0224 0.011125 -0.0101" rpy="0 0 0" />
    <parent link="br_shoulder" />
    <child link="br_thigh" />
    <axis xyz="0 0 1" />
    <limit lower="0" upper="0" effort="0" velocity="0" />
  </joint>
  <link name="br_calf">
    <inertial>
      <origin xyz="-0.00237381613529569 -0.034445498616468 -0.0226869436158008" rpy="0 0 0" />
      <mass value="0.0864459183664809" />
      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
    </inertial>
    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
  </link>
  <joint name="br_calf_joint" type="revolute">
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

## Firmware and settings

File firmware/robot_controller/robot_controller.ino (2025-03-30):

/******************************************************************
 * Harold Quadruped Robot Controller - SIMPLIFIED & ROBUST
 *
 * Features:
 * - Direct angle-to-pulse mapping with low-pass filtering for smoothness.
 * - Relies on accurate calibration to prevent drift.
 * - Precise timing control (200Hz loop).
 * - Robust communication and safety features.
 ******************************************************************/

#include <Wire.h>
#include <Adafruit_PWMServoDriver.h>
#include <math.h>    // Include for fabs, round, constrain
#include <string.h>  // Include for strcmp, strcpy, strtok_r
#include <stdlib.h>  // Include for atof
#include <ctype.h>   // Include for isdigit

//==========================//
//     GLOBAL CONSTANTS     //
//==========================//
#define MAX_MESSAGE_LENGTH 128
#define SERVO_FREQ 50            // Standard servo update rate
#define HANDSHAKE_MSG "ARDUINO_READY"

// Control timing parameters
#define CONTROL_INTERVAL_US 5000 // 5ms (200Hz) control loop
#define COMMAND_TIMEOUT_MS 1500  // Timeout before reverting to safe target angles
#define DEBUG_INTERVAL_MS 1000   // Interval for debug messages

// Servo physical limits (absolute pulse bounds)
#define SERVO_MIN_PULSE 150      // Absolute minimum pulse width the driver can send
#define SERVO_MAX_PULSE 600      // Absolute maximum pulse width the driver can send

// Smoothing Filter
// Lower value = more smoothing, slower response. Higher value = less smoothing, faster response.
// Good range: 0.02 (very smooth) to 0.2 (responsive)
#define PULSE_FILTER_ALPHA 0.05f // Low-pass filter coefficient for pulse smoothing

// Debug flag
#define DEBUG_OUTPUT 1           // Enable/disable Serial debug output

// Joint definitions
#define NUM_SERVOS 12
#define NUM_LEGS 4
#define JOINTS_PER_LEG 3

// Joint types (used for limits and safe pos)
#define SHOULDER 0
#define THIGH 1
#define KNEE 2

//==========================//
//    HARDWARE INTERFACE    //
//==========================//
Adafruit_PWMServoDriver pwm = Adafruit_PWMServoDriver();

//==========================//
//    JOINT CONFIGURATION   //
//==========================//
// Maps leg/joint type to servo index
const int legJointMap[NUM_LEGS][JOINTS_PER_LEG] = {
  {0, 4, 8},   // Front Left (shoulder, thigh, knee)
  {1, 5, 9},   // Front Right
  {2, 6, 10},  // Back Left
  {3, 7, 11}   // Back Right
};

// Servo calibration: Pulse width corresponding to min/max angles.
// !! CRITICAL FOR ACCURACY AND DRIFT PREVENTION !! MUST BE CALIBRATED !!
// Indices: 0-11 matching servo driver channels
int servoMinPulse[NUM_SERVOS] = {315, 305, 290, 360, 380, 185, 385, 215, 375, 185, 395, 185};
int servoMaxPulse[NUM_SERVOS] = {395, 225, 370, 280, 190, 375, 195, 405, 185, 375, 205, 375};
// Note: If a servo physically rotates opposite to convention, swap its min/max pulse values here.
// The mapping logic assumes minPulse corresponds to minAngle, maxPulse to maxAngle *after* any angle inversion.

// Joint Angle Limits (radians) - Used for clamping commands
// Defined per JOINT TYPE
const float jointMinAngle[JOINTS_PER_LEG] = {-0.35f, -0.79f, -0.79f}; // Shoulder, Thigh, Knee
const float jointMaxAngle[JOINTS_PER_LEG] = { 0.35f,  0.79f,  0.79f}; // Shoulder, Thigh, Knee
const float jointSafeAngle[JOINTS_PER_LEG] = { 0.0f,   0.3f,  -0.75f}; // Shoulder, Thigh, Knee

//==========================//
//       JOINT STATE        //
//==========================//
struct JointState {
  float targetAngleRad; // Target angle (radians) received from host
  float currentPulse;   // Current pulse width being sent (filtered value)
  uint8_t jointType;    // 0=Shoulder, 1=Thigh, 2=Knee (for limits/safe pos lookup)
  bool isLeftKnee;      // Flag for special mapping logic
};

JointState joints[NUM_SERVOS];

//==========================//
//   COMMUNICATION BUFFER   //
//==========================//
static char incomingBuffer[MAX_MESSAGE_LENGTH];
static int bufferIndex = 0;

//==========================//
//      TIMING CONTROL      //
//==========================//
static uint32_t lastControlMicros = 0;
static uint32_t lastCommandMillis = 0;

//==========================//
//    DIAGNOSTIC METRICS    //
//==========================//
// Simplified - just track command count and timeouts
uint32_t commandCount = 0;
uint32_t timeoutCount = 0;

//==========================//
//    FORWARD DECLARATIONS  //
//==========================//
void setupJoints();
void processSerialData();
void parseCommand(const char* command);
void moveToSafeTargetAngles();
float mapAngleToTargetPulse(int jointIdx, float angleRad);
void setServoPulse(int jointIdx, int pulse);
float constrainf(float x, float a, float b); // Explicit float constrain
int constrain(int x, int a, int b);        // Standard int constrain

//====================================================================
// SETUP
//====================================================================
void setup() {
  Serial.begin(115200);
  Serial.println("\nStarting Harold Controller (Simplified)...");

  // Send handshake early
  for (int i = 0; i < 3; i++) {
    Serial.println(HANDSHAKE_MSG);
    delay(20);
  }

  Serial.println("Initializing PWM driver...");
  pwm.begin();
  pwm.setOscillatorFrequency(27000000); // Verify for your PCA9685 board
  pwm.setPWMFreq(SERVO_FREQ);
  delay(100);
  Serial.println("PWM driver initialized.");

  // Configure initial joint states and move servos to safe position
  setupJoints();

  // Initialize timing
  lastCommandMillis = millis();
  lastControlMicros = micros();

  Serial.println("Controller ready.");
  Serial.println(HANDSHAKE_MSG); // Final handshake
}

//====================================================================
// MAIN LOOP
//====================================================================
void loop() {
  // 1. Process incoming serial data
  processSerialData(); // Updates joint target angles, resets command timer

  // 2. Run control loop at precise interval
  uint32_t currentMicros = micros();
  if (currentMicros - lastControlMicros >= CONTROL_INTERVAL_US) {
    lastControlMicros = currentMicros; // Update time for next interval

    // 3. Check for command timeout
    uint32_t currentMillis = millis(); // Get millis only once per loop
    if (currentMillis - lastCommandMillis > COMMAND_TIMEOUT_MS) {
      moveToSafeTargetAngles(); // Set target angles to safe values
      // Only log timeout periodically to avoid spam
      if (timeoutCount % 100 == 0) {
         Serial.println("Command timeout - Targets set to safe angles.");
      }
      timeoutCount++;
      // Don't reset lastCommandMillis here; let the next valid command do it.
    }

    // 4. Update all servos
    for (int i = 0; i < NUM_SERVOS; i++) {
      // 4a. Map the current target angle to a target pulse width using calibration
      // This function also handles angle clamping and knee inversion.
      float targetPulse = mapAngleToTargetPulse(i, joints[i].targetAngleRad);

      // 4b. Apply low-pass filter to the pulse width for smoothing
      // current = alpha * target + (1 - alpha) * current
      joints[i].currentPulse = (PULSE_FILTER_ALPHA * targetPulse) + ((1.0f - PULSE_FILTER_ALPHA) * joints[i].currentPulse);

      // 4c. Send the filtered pulse to the servo (setServoPulse handles absolute bounds)
      setServoPulse(i, (int)round(joints[i].currentPulse)); // Round to nearest integer pulse
    }

    // 5. Periodic Debug Output (throttled)
#if DEBUG_OUTPUT
    static uint32_t lastDebugTime = 0;
    if (currentMillis - lastDebugTime > DEBUG_INTERVAL_MS) {
        lastDebugTime = currentMillis;
        int j = 0; // Joint to debug (e.g., first shoulder)
        Serial.print("J"); Serial.print(j);
        Serial.print(" TgtAng: "); Serial.print(joints[j].targetAngleRad, 3);
        float targetPulseDebug = mapAngleToTargetPulse(j, joints[j].targetAngleRad);
        Serial.print(" TgtPulse: "); Serial.print(targetPulseDebug, 1);
        Serial.print(" CurPulse: "); Serial.println((int)round(joints[j].currentPulse));
    }
#endif
  } // End timed control loop

  // Less frequent tasks (e.g., idle handshake) - run outside timed loop
  static uint32_t lastIdleTaskTime = 0;
  uint32_t nowMillis = millis(); // Use cached millis if available
  if (nowMillis - lastIdleTaskTime > 2000) { // Check every 2 seconds
      lastIdleTaskTime = nowMillis;
      if (nowMillis - lastCommandMillis > 5000) { // If idle for 5 seconds
          Serial.println(HANDSHAKE_MSG); // Send keep-alive handshake
      }
  }

} // End main loop

//====================================================================
// JOINT SETUP
//====================================================================
void setupJoints() {
  Serial.println("Setting up initial joint states...");
  for (int leg = 0; leg < NUM_LEGS; leg++) {
    for (int joint = 0; joint < JOINTS_PER_LEG; joint++) {
      int idx = legJointMap[leg][joint];
      if (idx < 0 || idx >= NUM_SERVOS) {
          Serial.print("ERROR: Invalid servo index "); Serial.print(idx);
          Serial.print(" for leg "); Serial.print(leg); Serial.print(", joint "); Serial.println(joint);
          continue; // Skip invalid configuration
      }

      joints[idx].jointType = joint; // Store type (SHOULDER, THIGH, KNEE)
      joints[idx].isLeftKnee = (joint == KNEE && (leg == 0 || leg == 2)); // Legs 0 (FL) and 2 (BL) are left

      // Set initial target angle to the safe angle for this joint type
      joints[idx].targetAngleRad = jointSafeAngle[joint];

      // Calculate the initial pulse corresponding to the safe angle
      // Map directly, don't filter yet
      float initialPulse = mapAngleToTargetPulse(idx, joints[idx].targetAngleRad);
      joints[idx].currentPulse = initialPulse; // Initialize currentPulse

      // Move servo directly to initial pulse
      setServoPulse(idx, (int)round(initialPulse));
      delay(15); // Small delay for servo to start moving
    }
  }
  Serial.println("Joints set to safe angles. Allowing servos to settle...");
  delay(1000); // Wait for servos to reach initial position
  Serial.println("Joint setup complete.");
}

//====================================================================
// ANGLE TO PULSE MAPPING (Core Calibration Logic)
//====================================================================
// Maps a requested angle (radians) to the target servo pulse width.
// Handles joint limits, knee inversion, and calibration values.
float mapAngleToTargetPulse(int jointIdx, float angleRad) {
    // 1. Get joint type specific limits and safe angle
    uint8_t type = joints[jointIdx].jointType;
    float minAngle = jointMinAngle[type];
    float maxAngle = jointMaxAngle[type];

    // 2. Handle Left Knee Inversion: Invert angle *before* clamping
    float angleToProcess = angleRad;
    if (joints[jointIdx].isLeftKnee) {
        angleToProcess = -angleRad;
    }

    // 3. Clamp the angle (after potential inversion) to the joint's limits
    angleToProcess = constrainf(angleToProcess, minAngle, maxAngle);

    // 4. Get calibrated pulse range for this specific servo
    int minPulse = servoMinPulse[jointIdx];
    int maxPulse = servoMaxPulse[jointIdx];

    // 5. Perform linear mapping from angle range to pulse range
    float angleRange = maxAngle - minAngle;
    float pulseRange = (float)(maxPulse - minPulse); // Ensure float calculation

    float normalizedPos = 0.0f;
    // Avoid division by zero if angle range is negligible
    if (fabs(angleRange) > 1e-6) {
        normalizedPos = (angleToProcess - minAngle) / angleRange;
    }

    // Clamp normalized position just in case (shouldn't be needed if angle clamped)
    normalizedPos = constrainf(normalizedPos, 0.0f, 1.0f);

    float targetPulse = (float)minPulse + normalizedPos * pulseRange;

    return targetPulse; // Return the calculated target pulse (float)
}

//====================================================================
// SET SERVO PULSE
//====================================================================
// Sets the PWM pulse for a servo, constraining to absolute limits.
void setServoPulse(int jointIdx, int pulse) {
  // Constrain to the absolute physical limits of the PWM driver/servo
  pulse = constrain(pulse, SERVO_MIN_PULSE, SERVO_MAX_PULSE);
  pwm.setPWM(jointIdx, 0, pulse);
}

//====================================================================
// MOVE TO SAFE ANGLES
//====================================================================
// Sets the *target* angle for all joints to their safe values.
// The filtering in the main loop will handle the smooth transition.
void moveToSafeTargetAngles() {
  bool changed = false;
  for (int i = 0; i < NUM_SERVOS; i++) {
    float safeAngle = jointSafeAngle[joints[i].jointType];
    // Only update if not already targeting safe angle (within tolerance)
    if (fabs(joints[i].targetAngleRad - safeAngle) > 1e-5) {
        joints[i].targetAngleRad = safeAngle;
        changed = true;
    }
  }
  // if (changed && DEBUG_OUTPUT) { // Reduce spam
  //   Serial.println("Targets updated to safe angles.");
  // }
}

//====================================================================
// SERIAL COMMUNICATION
//====================================================================
void processSerialData() {
    // Quick check for handshake request 'R' before buffering
    if (Serial.peek() == 'R') {
         String maybeReady = "";
         unsigned long readStart = millis();
         // Read quickly to check for "READY?#" pattern
         while (Serial.available() > 0 && (millis() - readStart < 50) && maybeReady.length() < 10) {
             char c = (char)Serial.read();
             maybeReady += c;
             if (c == '#') break;
         }

         if (maybeReady.indexOf("READY?") != -1) {
             // Respond to handshake
             for(int i=0; i<3; ++i) { Serial.println(HANDSHAKE_MSG); delay(5); }
             lastCommandMillis = millis(); // Treat handshake as activity
             bufferIndex = 0; incomingBuffer[0] = '\0'; // Clear buffer
             while(Serial.available() > 0) Serial.read(); // Consume rest of line
             return; // Handled
         } else {
             // Not handshake, put read data into main buffer
              if (bufferIndex + maybeReady.length() < MAX_MESSAGE_LENGTH -1) {
                  memcpy(incomingBuffer + bufferIndex, maybeReady.c_str(), maybeReady.length());
                  bufferIndex += maybeReady.length();
                  incomingBuffer[bufferIndex] = '\0';
              } else {
                   Serial.println("ERR: Buffer overflow on non-handshake read");
                   bufferIndex = 0; incomingBuffer[0] = '\0';
              }
         }
    }

  // Read remaining chars into buffer until '#' or full
  while (Serial.available() > 0 && bufferIndex < (MAX_MESSAGE_LENGTH - 1)) {
    char c = (char)Serial.read();
    if (c == '\r' || c == '\n') continue; // Ignore newline/CR

    if (c == '#') { // End of command found
      incomingBuffer[bufferIndex] = '\0'; // Terminate string
      if (bufferIndex > 0) {
        parseCommand(incomingBuffer); // Process the complete command
      }
      bufferIndex = 0; // Reset for next command
    } else {
      incomingBuffer[bufferIndex++] = c; // Add char to buffer
    }
  }

  // Handle buffer overflow if '#' wasn't found
  if (bufferIndex >= (MAX_MESSAGE_LENGTH - 1)) {
    Serial.println("ERR: Command buffer overflow, discarding.");
    bufferIndex = 0;
    incomingBuffer[0] = '\0';
  }
}

// Parses a complete command string from the buffer
void parseCommand(const char* command) {
  // Handle simple string commands
  if (strcmp(command, "STATUS") == 0) {
#if DEBUG_OUTPUT
    Serial.print("STATUS: OK Cmds:"); Serial.print(commandCount);
    Serial.print(" Timeouts:"); Serial.println(timeoutCount);
#endif
    lastCommandMillis = millis(); // Acknowledge command
    return;
  }
  if (strcmp(command, "STOP") == 0) {
#if DEBUG_OUTPUT
    Serial.println("STOP received - moving to safe angles & stopping.");
#endif
    moveToSafeTargetAngles();
    // Force servos immediately to calculated safe pulse (bypass filter)
    for (int i = 0; i < NUM_SERVOS; i++) {
      float safePulse = mapAngleToTargetPulse(i, joints[i].targetAngleRad);
      joints[i].currentPulse = safePulse; // Update state immediately
      setServoPulse(i, (int)round(safePulse));
    }
    lastCommandMillis = millis(); // Acknowledge command
    return;
  }
  if (strcmp(command, "READY?") == 0) { // Should be handled by pre-check, but safety
     for(int i=0; i<3; ++i) Serial.println(HANDSHAKE_MSG);
     lastCommandMillis = millis();
     return;
  }

  // --- Attempt to parse 12 joint angles ---
  int jointIdx = 0;
  char commandCopy[MAX_MESSAGE_LENGTH]; // Create mutable copy for strtok_r
  strncpy(commandCopy, command, MAX_MESSAGE_LENGTH - 1);
  commandCopy[MAX_MESSAGE_LENGTH - 1] = '\0';

  char* valueStr;
  char* rest = commandCopy;
  bool parseError = false;
  float parsedAngles[NUM_SERVOS]; // Temporary storage

  while (jointIdx < NUM_SERVOS && (valueStr = strtok_r(rest, ",", &rest))) {
    if (*valueStr == '\0') { parseError = true; break; } // Handle empty token ",,"

    // Use strtof for potentially better error checking than atof if needed
    // char* endPtr;
    // float value = strtof(valueStr, &endPtr);
    // if (endPtr == valueStr) { parseError = true; break; } // No conversion happened
    float value = atof(valueStr); // Simpler atof for now

    parsedAngles[jointIdx] = value;
    jointIdx++;
  }

  // Validate parsing result
  if (jointIdx == NUM_SERVOS && !parseError) {
    // Successfully parsed 12 values - Update target angles
    for (int i = 0; i < NUM_SERVOS; ++i) {
      // Clamping happens inside mapAngleToTargetPulse, just store the raw target
      joints[i].targetAngleRad = parsedAngles[i];
    }
    lastCommandMillis = millis(); // Reset command timer
    commandCount++;
#if DEBUG_OUTPUT && 0 // Verbose logging - disable by default
    if (commandCount % 20 == 1) {
        Serial.print("CMD OK("); Serial.print(commandCount); Serial.print("): Tgt0=");
        Serial.println(joints[0].targetAngleRad, 3);
    }
#endif
  } else {
#if DEBUG_OUTPUT
    Serial.print("ERR: Invalid angle command. Parsed ");
    Serial.print(jointIdx); Serial.print("/"); Serial.print(NUM_SERVOS);
    if(parseError) Serial.print(" (parse error)");
    Serial.print(". CMD:["); Serial.print(command); Serial.println("]");
#endif
  }
}

//====================================================================
// UTILITY FUNCTIONS
//====================================================================

// Float constrain (standard library might not have it)
float constrainf(float x, float a, float b) {
    if(x < a) return a;
    if(x > b) return b;
    return x;
}

// Integer constrain (standard library usually has this)
int constrain(int x, int a, int b) {
    if(x < a) return a;
    if(x > b) return b;
    return x;
}

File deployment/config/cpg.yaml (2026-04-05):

# CPG Configuration - Matched to hardware (Session 41)
# DO NOT MODIFY without updating simulation ScriptedGaitCfg/CPGCfg

# Gait timing
frequency_hz: 0.4        # Session 41: softer gait (longer cycle reduces impact)
duty_cycle: 0.5          # 50% stance / 50% swing to slow the lift/plant

# Leg trajectory angles (radians)
trajectory:
  swing_thigh: 0.54      # Session 36: -30.65 deg hardware -> +30.65 deg sim
  stance_thigh: 0.67     # Session 36: -38.15 deg hardware -> +38.15 deg sim
  stance_calf: -0.87     # Session 36: 50 deg hardware -> -50 deg sim
  swing_calf: -1.3963    # Session 36: 80 deg hardware -> -80 deg sim
  shoulder_amplitude: 0.0096  # Session 36: 0.55 deg hardware -> 0.0096 rad sim
  thigh_offset_front: 0.05    # Bias front thighs forward (rad)
  thigh_offset_back: -0.05    # Bias rear thighs back (rad)

# Control loop
control:
  rate_hz: 20            # Control frequency (50ms period)
  action_filter_beta: 0.40  # Session 35: Optimal (0.50 too strong, 0.35 OK but 0.40 best)

# Joint action ranges (for scaling policy output)
joint_range:
  shoulder: 0.30         # ±0.30 rad from default
  thigh: 0.90            # ±0.90 rad from default
  calf: 0.90             # ±0.90 rad from default

# Default joint positions (ready stance) live in config/stance.yaml.
# Do NOT duplicate them here; the runtime loads stance.yaml directly.

# Joint sign for convention conversion (RL <-> Hardware)
# Multiply relative positions by this to convert: rl_rel = hw_rel * joint_sign
# Shoulders are NOT mirrored here; right-side servo mounting is already handled
# by the firmware/hardware direction tables.
joint_sign:
  shoulders: 1.0
  thighs: -1.0           # Inverted
  calves: -1.0           # Inverted

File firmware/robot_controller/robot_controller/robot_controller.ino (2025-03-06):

#include <Wire.h>
#include <Adafruit_PWMServoDriver.h>

//==========================//
//     USER ADJUSTMENTS     //
//==========================//
#define MAX_MESSAGE_LENGTH 256
#define SERVO_FREQ 50
#define HANDSHAKE_MSG "ARDUINO_READY"

// Control loop interval and command timeout (in ms)
#define CONTROL_INTERVAL 5     // Control loop interval (5 ms)
#define COMMAND_TIMEOUT 100    // If no valid command in 100 ms, revert to safe posture

// PD Controller Gains for the discrete controller.
// These values have been updated to more closely match the simulation's implicit PD controller
// Simulation values: stiffness=40.0, damping=75.0, effort_limit=0.8
float PD_Kp = 4.0;      // Proportional gain - scaled from simulation stiffness
float PD_Kd = 1.2;      // Derivative gain - scaled from simulation damping
float PD_EFFORT_LIMIT = 0.8;  // Maximum control effort (matches simulation)

//==========================//
// SERVO & ANGLE VARIABLES  //
//==========================//
Adafruit_PWMServoDriver pwm = Adafruit_PWMServoDriver(); // default address 0x40

// Ring-buffer for incoming serial data
static char incomingBuffer[MAX_MESSAGE_LENGTH];
static int bufferIndex = 0;

// We have 12 servos (indices 0..11).
// currentPos: estimated joint positions (radians)
// targetPos: commanded joint positions (radians)
// prevPos: previous current positions (for velocity estimation)
static float currentPos[12] = {0, 0, 0, 0, 0, 0, 0, 0, 0, 0, 0, 0};
static float targetPos[12]  = {0, 0, 0, 0, 0, 0, 0, 0, 0, 0, 0, 0};
static float prevPos[12]    = {0, 0, 0, 0, 0, 0, 0, 0, 0, 0, 0, 0};

// Define safe (default) positions
static float safePos[12] = {0.0, 0.0, 0.0, 0.0, 0.3, 0.3, 0.3, 0.3, -0.75, -0.75, -0.75, -0.75};

// Min / max values are mirrored so that "positive" and "negative" positions all mean the same thing
int SERVO_MIN[12]    = {315, 305, 290, 360,   380, 185, 385, 215,   375, 185, 395, 185};
int SERVO_MAX[12]    = {395, 225, 370, 280,   190, 375, 195, 405,   185, 375, 205, 375};

// Angular limits in radians for each servo (set to match simulation parameters)
// For shoulder joints, a small range; for thigh and knee, a wider range.
static float ANGLE_MAX[12] = {
  0.3491, 0.3491, 0.3491, 0.3491, 0.7853, 0.7853, 0.7853, 0.7853, 0.7853, 0.7853, 0.7853, 0.7853
};

static float ANGLE_MIN[12] = {
  -0.3491, -0.3491, -0.3491, -0.3491, -0.7853, -0.7853, -0.7853, -0.7853, -0.7853, -0.7853, -0.7853, -0.7853
};


// For the control loop
static unsigned long lastControlTime = 0;
static unsigned long lastCommandTime = 0;

//----------------------------------------------------------
// setup()
//----------------------------------------------------------
void setup() {
  Serial.begin(115200);
  while (!Serial);
  Serial.println(HANDSHAKE_MSG); // Announce readiness immediately
  
  pwm.begin();
  pwm.setOscillatorFrequency(27000000);
  pwm.setPWMFreq(SERVO_FREQ);
  delay(1000);
  Serial.println("\nCOMMUNICATION LINK ESTABLISHED...");
  startServos();
}

//----------------------------------------------------------
// startServos()
// Moves each servo to its initial (safe) position at startup.
//----------------------------------------------------------
void startServos() {
  Serial.println("STARTING SERVOS...");
  for (int i = 0; i < 12; i++) {
    float anglePct = (safePos[i] - ANGLE_MIN[i]) / (ANGLE_MAX[i] - ANGLE_MIN[i]);
    if (anglePct < 0.0) anglePct = 0.0;
    if (anglePct > 1.0) anglePct = 1.0;
    float servoRange = SERVO_MAX[i] - SERVO_MIN[i];
    float pulse = (anglePct * servoRange) + SERVO_MIN[i];
    pwm.setPWM(i, 0, pulse);
    currentPos[i] = safePos[i];
    prevPos[i] = safePos[i];
    // Initialize targetPos to safe positions
    targetPos[i] = safePos[i];
    delay(250);
  }
  // Also initialize the last command time to now.
  lastCommandTime = millis();
  Serial.println("STARTUP COMPLETE!");
}

//----------------------------------------------------------
// isValidNumericChar()
//----------------------------------------------------------
bool isValidNumericChar(char c) {
  return (isDigit(c) || c == '.' || c == '-');
}

//----------------------------------------------------------
// messageDecode()
// Parses up to 12 comma-separated floats from the incoming message.
//----------------------------------------------------------
bool messageDecode(const char* buffer) {
  String angleStr = "";
  int servoCount = 0;
  
  // Handle handshake request.
  if (strstr(buffer, "READY?") != NULL) {
    Serial.println(HANDSHAKE_MSG);
    return false; // Not a position command.
  }
  
  for (int i = 0; i < MAX_MESSAGE_LENGTH; i++) {
    char c = buffer[i];
    if (c == '\0') break;
    if (c == ',') {
      if (angleStr.length() > 0) {
        if (servoCount < 12) {
          targetPos[servoCount] = angleStr.toFloat();
          servoCount++;
          angleStr = "";
        } else {
          Serial.println("ERROR: Too many servo values received");
          return false;
        }
      }
    } else {
      if (isValidNumericChar(c)) {
        angleStr += c;
      }
    }
  }
  if (angleStr.length() > 0) {
    if (servoCount < 12) {
      targetPos[servoCount] = angleStr.toFloat();
      servoCount++;
    } else {
      Serial.println("ERROR: Too many servo values received");
      return false;
    }
  }
  if (servoCount != 12) {
    Serial.print("WARNING: Received incorrect number of servo values: ");
    Serial.println(servoCount);
    return false;
  }
  // Update the time of the last valid command.
  lastCommandTime = millis();
  Serial.println("\nACK: Position command received");
  return true;
}
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

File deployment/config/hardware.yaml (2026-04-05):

# Hardware Configuration - Harold Robot
# Matched to ESP32 firmware (HaroldStreamingControl)

# ESP32 Communication
esp32:
  port: /dev/ttyUSB0     # USB serial port (may vary)
  baud: 115200           # Baud rate
  timeout_ms: 50         # Read timeout

# IMU (MPU6050)
imu:
  bus: 1                 # I2C bus number
  address: 0x68          # I2C address
  sample_rate_hz: 100    # Sample rate for velocity estimation

# Servo Configuration (FeeTech ST3215)
servos:
  # Servo IDs (1-indexed, matches firmware)
  ids:
    fl_shoulder: 1
    fl_thigh: 2
    fl_calf: 3
    fr_shoulder: 4
    fr_thigh: 5
    fr_calf: 6
    bl_shoulder: 7
    bl_thigh: 8
    bl_calf: 9
    br_shoulder: 10
    br_thigh: 11
    br_calf: 12

  # Joint order in policy output (RL convention)
  joint_order:
    - fl_shoulder
    - fr_shoulder
    - bl_shoulder
    - br_shoulder
    - fl_thigh
    - fr_thigh
    - bl_thigh
    - br_thigh
    - fl_calf
    - fr_calf
    - bl_calf
    - br_calf

  # Sign correction: RL -> hardware
  # Shoulder semantics stay the same on every leg.
  # Right-side servo mirroring is handled by `direction`, not by flipping the
  # high-level shoulder sign convention.
  joint_sign:
    shoulders: 1.0
    thighs: -1.0
    calves: -1.0

  # Hardware direction (from firmware DIR array)
  # Positive = servo increases with positive angle
  direction:
    1: 1    # FL shoulder
    2: 1    # FL thigh
    3: 1    # FL calf
    4: -1   # FR shoulder
    5: -1   # FR thigh
    6: -1   # FR calf
    7: 1    # BL shoulder
    8: 1    # BL thigh
    9: 1    # BL calf
    10: -1  # BR shoulder
    11: -1  # BR thigh
    12: -1  # BR calf

  # Safe joint limits (more conservative than simulation)
  safe_limits_deg:
    shoulder: [-25, 25]   # ±25° (sim allows ±30°)
    thigh: [-55, 5]       # -55° to +5° (forward lean only)
    calf: [-5, 80]        # -5° to +80° (extension safe)

  # Servo parameters
  units_per_deg: 11.378   # 4096 / 360
  mid_position: 2047      # Servo mid-point
  speed: 1600             # Units/sec for gait
  acceleration: 100       # Units/sec² ramp

# Safety thresholds
safety:
  load_warning: 70        # % load warning
  load_critical: 90       # % load emergency stop
  temperature_max: 50     # °C max servo temp
  watchdog_ms: 250        # Command timeout

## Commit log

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2025-03-06 Improve PD controller to match simulation parameters
    - Increase proportional gain from 1.5 to 4.0 to better match simulation stiffness
    - Increase derivative gain from 0.5 to 1.2 to better match simulation damping
    - Add effort limiting at 0.8 to match simulation's effort_limit
    - Improve code comments to document simulation parameters
    [robot_controller.ino]
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2025-03-29 TEST1: Completely rewrite robot controller to fix jitter and drift issues
    - Implemented proper PID control with anti-drift mechanisms
    - Added low-pass filtering to reduce jitter
    - Improved timing precision using microseconds
    - Added robust movement interpolation
    - Enhanced error handling and safety features
    - Updated README with comprehensive hardware information
    [robot_controller.ino]
2025-03-29 TEST1-fix: Replace strtof with atof for better Arduino compatibility
    - Fixed 'strtof not declared in this scope' compilation error
    - Replaced strtof with a more robust parsing approach using atof
    - Added proper handling of numeric values in command parsing
    [robot_controller.ino]
2025-03-29 TEST1-fix: Fix handshake message to match Python controller
    - Changed handshake message from 'HAROLD_READY' to 'ARDUINO_READY'
    - Fixed compatibility with existing Python control code
    - Ensures proper initialization and communication
    [robot_controller.ino]
2025-03-29 TEST1-fix: Robust handshake protocol and serial communication
    - Completely rewrote handshake protocol to ensure reliable detection
    - Added direct handshake detection in the main loop
    - Improved serial data handling and command processing
    - Sends multiple handshake responses to increase reception reliability
    [robot_controller.ino]
2025-03-29 TEST1-fix: Optimize memory and servo issues
    - Fixed inverted servo min/max values for joints 8-11
    - Optimized memory usage (reduced dynamic memory by ~40%)
    - Increased command timeout from 250ms to 1000ms
    - Added detailed debugging and status reporting
    - Fixed filter mechanism for smoother motion
    - Tuned PID parameters for better responsiveness
    [robot_controller.ino]
2025-03-29 TEST1-fix: Resolve jointLimits conflict error
    - Fixed conflicting declarations of jointLimits
    - Renamed old array to jointAngles to avoid conflict
    - Updated validatePositions() to use the struct-based jointLimits
    - Fixed incorrect references to removed struct fields
    [robot_controller.ino]
2025-03-29 TEST1-fix: Fix left knee joint direction
    - Inverted direction for left knee joints (8 and 10) to ensure backward extension
    - Added special handling in mapAngleToServo function for left knees
    - Improved documentation of joint indexing and direction convention
    - Fixed knees now move in the correct direction matching the right side
    [robot_controller.ino]
2025-03-29 TEST1-fix: Comprehensive fixes for knee direction and movement issues
    - Fixed left knee (8, 10) direction issues by inverting angles before mapping
    - Added explicit joint identification by mapping joint index to leg/type
    - Increased PID gains and effort limits for more torque and movement
    - Added movement test sequence at startup to verify servo response
    - Enhanced logging with servo commands and pulse values
    - Properly inverted safe positions for left knees to match right knees
    [robot_controller.ino]
2025-03-29 TEST1-fix: Enhanced handshake protocol for reliable detection
    - Repeated handshake message at startup (10 times)
    - Added periodic handshake broadcast when idle
    - Improved handshake response with multiple messages
    - Implemented more aggressive handshake detection and response
    - Fixed timing to ensure Python controller successfully detects handshake
    [robot_controller.ino]
2025-03-29 TEST1-fix: Extreme handshake enhancement for guaranteed detection
    - Complete rewrite of handshake mechanism for maximum reliability
    - Send 50 handshake messages at startup before any initialization
    - Add another 20 messages after PWM driver init but before servo setup
    - Completely redesigned main loop to catch any potential handshake requests
    - Relaxed matching to detect partial 'READY' strings
    - Shortened handshake broadcast interval to 100ms when idle
    [robot_controller.ino]
2025-03-30 TEST1-fix: Complete controller overhaul for reliable movement
    - Increased PID gain and power parameters (PID_KP raised to 12.0)
    - Added immediate servo updates when commands received
    - Fixed left knee angle handling consistently throughout code
    - Added detailed movement debugging and diagnostics
    - Completely rewritten code with correct handling of all functions
    - Added startup movement test to verify servo functionality
    - Optimized command parsing for faster response
    [robot_controller.ino]
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2025-03-30 TEST1-fix: Diagnostic mode for servo movement troubleshooting
    - Added direct servo testing at startup to verify hardware
    - Implemented extreme debugging mode with detailed servo state logging
    - Added forced test movements to check servo responsiveness
    - Reduced handshake message frequency to avoid console flooding
    - Improved debug diagnostics throughout servo control flow
    [robot_controller.ino]
2025-03-30 TEST1-fix: Memory optimization for Arduino
    - Disabled debug features by default to save memory
    - Made extreme debugging conditional using preprocessor macros
    - Simplified status and feedback functions
    - Reduced string lengths throughout codebase
    - Simplified test movement function for memory savings
    - Made direct servo test conditionally compiled
    [robot_controller.ino]
2025-03-30 Fix jerky movement and dangerous exit behavior
    - Added STOP command handler to immediately halt servos on shutdown
    - Reduced filter coefficients for smoother motion (0.8 → 0.6)
    - Improved emergency shutdown with multi-stage safe position
    - Added safety protocol for program termination
    - Ensured proper safe position return before closing
    [robot_controller.ino]
2025-03-30 Fix joint drift issues with advanced PID control
    - Implemented conditional integral accumulation to prevent drift
    - Added zero-crossing detection for smarter integral control
    - Added small-error integral term reset for positional stability
    - Implemented anti-drift mechanism for very small movements
    - Adjusted PID parameters (reduced KI from 0.1 to 0.01)
    - Increased derivative gain for more damping (KD from 0.5 to 1.0)
    [robot_controller.ino]
2025-03-30 Dramatically improve motion smoothness
    - Implemented acceleration limiting to prevent jerky movements
    - Significantly reduced filter coefficients (FILTER_ALPHA: 0.6 → 0.3, VELOCITY_ALPHA: 0.6 → 0.2)
    - Cut proportional gain in half (PID_KP: 10.0 → 5.0) for smoother control
    - Increased derivative damping (PID_KD: 1.0 → 1.5) to reduce oscillations
    - Added sophisticated velocity and acceleration limiting system
    - Reduced maximum effort (PID_EFFORT_LIMIT: 1.5 → 0.8) for smoother transitions
    [robot_controller.ino]
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2025-04-28 Fixed assembly origins and axis, rebuit the full assembly and re-exported the URDF
    [(Left Mirror)STS3215.SLDPRT, (left mirror)body middle front right.SLDPRT, Body.STL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]
2025-04-28 redid URDF export and assemblies with the old orientations, but with the sizing and origins fixed
    [Body.STL, Harold.SLDASM, Harold_URDF_Export.csv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]
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2025-04-29 Gave up on trying to import the URDF directly. Started manually importing the corrected STL files and moving them in to place.
    [left_calf.blend, left_calf.stl, left_knee.blend]
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2025-05-04 Switched to the correct ESP32 firmware files. Slightly modified CalibrationOfs.ino to print success or fail feedback
    [Ping.ino]
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2025-05-22 Coming back after travelling, not sure what the most recent unpushed changes are. This should be a stable reset point.
    [CalibrateMiddles.ino, Ping.ino]
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2025-06-13 Changing the sim seed fixed the NaN training collapse, I reduced the command sampling to -0.5 and 0.5
    [skrl_ppo_cfg.yaml]
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2025-12-20 Enhance flat terrain reward structure and configuration
    - Increased forward progress rewards and adjusted penalties to refine performance incentives.
    - Introduced a rear support bonus to encourage proper stance during movement.
    - Updated target height in gait configuration for improved stability.
    - Adjusted minimum log standard in PPO configuration to enhance exploration during training.
    [skrl_ppo_cfg.yaml]
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2025-12-24 Update experiment documentation and configurations following Sessions 15 and 16
    - Revised CONTEXT.md to reflect the latest findings, including the discovery of backward drift as a stable attractor and the failure of various PPO tuning and forward gating approaches.
    - Updated EXPERIMENTS.md to document the results of Sessions 15 and 16, highlighting key findings and adjustments made to reward structures and configurations.
    - Enhanced NEXT_STEPS.md to prioritize checkpoint selection and the introduction of an explicit backward penalty to address the backward drift issue.
    - Adjusted reward configurations in harold_isaac_lab_env_cfg.py to revert diagonal gait reward to the best stable configurat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
    [skrl_ppo_cfg.yaml]
2025-12-25 Document findings from Session 18 and update configurations
    - Analyzed techniques from AnyMal and Spot reference implementations, confirming that all tested methods worsened performance for Harold.
    - Updated EXPERIMENTS.md to reflect the results of Session 18, emphasizing the need for different reward tuning due to Harold's lighter weight.
    - Revised NEXT_STEPS.md to prioritize the implementation of exponential velocity tracking and adjustments to reward magnitudes.
    - Adjusted harold_isaac_lab_env_cfg.py to revert to optimal configurations based on recent experiments, including the backward motion penalty.
    - Enhanced harold_isaac_lab_env.py to disable ineffective techniques and refine the rew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
    [skrl_ppo_cfg.yaml]
2025-12-27 Document breakthroughs from Session 21 and update configurations
    - Highlighted the critical discovery that the previous "Phase 1 failed" conclusion was incorrect; the robot can walk with open-loop scripted control after adjusting PD gains.
    - Updated CONTEXT.md to reflect the new best performance of vx=+0.141 m/s achieved with increased stiffness and damping settings.
    - Revised EXPERIMENTS.md to document the successful scripted gait validation and the implications for future RL training with corrected PD gains.
    - Enhanced NEXT_STEPS.md to prioritize re-training RL with the new actuator settings and validate them on hardware.
    - Adjusted harold_isaac_lab_env_cfg.py to incorporate the new script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
    [CalibrateMiddles.ino, ResetServoOffset.ino]
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2025-12-29 Add collision-safe limits, 100% torque, and servo tuning utility
    Firmware changes (HaroldStreamingControl.ino):
    - Set TORQUE_LIMIT=1000 (100% max) at boot via initServoTorque()
    - Asymmetric collision-safe joint limits matching validated scripted gait
    - Thighs: -55° to +5° (prevents body collision)
    - Calves: -5° to +80°
    - Shoulders: ±20°
    - Reduce watchdog timeout from 25s to 250ms for safety
    New utility (ServoTuning.ino):
    - Diagnose servo dead zones and position drift
    - Commands: scan (s), read params (r), set dead zone (d/a), calibrate (c), monitor (m)
    - Targets registers 26-27 (CW/CCW dead zone) for responsiveness tuning
    Session 27: Pi 5 stress tests passed (no undervoltage un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
    [HaroldStreamingControl.ino, ServoTuning.ino]
2025-12-29 Session 27: Document gear backlash finding and priority experiment
    Extended ServoTuning.ino with raw register access (x, X, W commands).
    Discovered servo "dead zone" is actually mechanical gear backlash (~1-3°).
    Key findings:
    - Dead zone registers already at minimum (1 step = 0.088°)
    - P coefficient (reg 21) = 32 factory; P=200 causes oscillations
    - Gear backlash is hardware limitation, must model in simulation
    Priority experiment for overnight run:
    - Increase joint_position_noise to 0.035 rad (~2°) to simulate backlash
    - Test policy robustness to position uncertainty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
    [ServoTuning.ino]
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2025-12-30 Update Session 30: Joint Limit Alignment & CPG Optimization
    - Achieved alignment of joint limits with hardware safe ranges, ensuring compatibility for all joints.
    - Optimized CPG frequency to 0.7 Hz, confirmed as the best setting through frequency sweep experiments.
    - Exported the best policy (EXP-170) with a forward velocity of 0.018 m/s for hardware deployment.
    - Documented findings on the failure of external perturbations to maintain stability, emphasizing the need for controlled environments during training.
    - Updated configuration files to reflect changes in joint limits and CPG settings for deployment readiness.
    [cpg.yaml]
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2025-12-31 Session 34: Large amplitude CPG for backlash tolerance
    Hardware test (Session 33) revealed ~30° servo backlash absorbing
    entire calf swing motion (26°). This session increases amplitudes
    to exceed backlash zone:
    - Calf: 26° → 50° (swing_calf -1.38, stance_calf -0.50)
    - Thigh: 29° → 40° (swing_thigh 0.25, stance_thigh 0.95)
    Training result: vx=0.020 m/s, WALKING (no regression)
    Ready for hardware test to verify feet actually lift.
    [cpg.yaml]
2025-12-31 Session 35: Smooth gait - damping=60, beta=0.35
    Hardware test of Session 34 showed jerky gait with harsh shock absorption.
    This session increases damping and action filtering for smoother motion:
    - damping: 30 → 60 (reduces oscillations at contact)
    - action_filter_beta: 0.18 → 0.35 (stronger EMA smoothing)
    Training result: vx=0.016 m/s, WALKING (slightly lower than 0.020)
    Ready for hardware test to verify smoothness improvement.
    [cpg.yaml]
2025-12-31 Session 35: Smooth gait optimization
    Hardware test showed jerky gait with harsh shock absorption. This session
    systematically optimized smoothing parameters through 7 experiments.
    Optimal settings found:
    - damping: 30 → 75 (reduces oscillations at contact)
    - action_filter_beta: 0.18 → 0.40 (stronger EMA smoothing)
    - torque_penalty: -0.005 → -0.01 (penalizes high torques)
    - action_rate_penalty: 0 → -0.1 (new, penalizes rapid action changes)
    Experiments summary:
    - 35a: damping=60, beta=0.35 → vx=0.016 WALKING
    - 35b: strong penalties → vx=0.002 STANDING (too strong)
    - 35c: balanced → vx=0.017 WALKING ✓
    - 35d: beta=0.50 → vx=0.009 STANDING (too strong)
    - 35e: 0.5 Hz CPG → v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
    [cpg.yaml]
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2026-01-02 Session 38 Extended: Document findings from autonomous experimentation with CPG and RL approaches. Key insights include the failure of CPG mode, the need for environment investigation, and the conclu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
    [cpg.yaml]
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2026-01-03 Update default pose parameters for Harold robot to improve stance consistency across configurations
    - Adjusted thigh and calf values in `test_sign_conversion.py`, `cpg.yaml`, `action_converter.py`, and `observation_builder.py` to -1.05 for calves and 0.40 for thighs.
    - Updated corresponding values in the firmware for consistency.
    - Added new session CSV files for logging hardware performance during tests.
    These changes aim to enhance the robot's stability and performance during operation.
    [session_2026-01-03_19-04-36.csv, session_2026-01-03_19-13-02.csv, session_2026-01-03_19-16-43.csv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]
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2026-01-04 Refine gait dynamics and documentation for Harold robot
    - Updated `cpg.yaml`, `cpg_generator.py`, and `scripted_gait_test_1.ino` to implement a duty-cycle aware gait, enhancing the stance and swing phases for improved leg clearance.
    - Adjusted trajectory design in `harold_isaac_lab_env.py` and `harold_isaac_lab_env_cfg.py` to reflect the new duty-cycle mechanics, ensuring alignment with hardware capabilities.
    - Enhanced comments and documentation across files to clarify the impact of duty cycle on gait performance.
    These changes aim to optimize the robot's walking dynamics and ensure consistency across simulation and hardware implementations.
    [cpg.yaml]
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2026-03-14 Migrate to Isaac Lab v2.3.2 + Isaac Sim 5.1.0 and clean up stale artifacts
    - Remove dump_pickle imports/calls (removed in Isaac Lab v2.3.2) from all 4 train scripts
    - Update pretrained_checkpoint import path (moved to isaaclab_rl) in all 4 play scripts
    - Replace deprecated attach_yaw_only with ray_alignment in all 3 env configs
    - Update skrl config from STATES to OBSERVATIONS keyword in all 3 PPO configs
    - Remove tracked __pycache__/.pyc files that should have been gitignored
    [skrl_ppo_cfg.yaml]
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2026-03-14 autoresearch: increase rollouts from 24 to 48
    Hypothesis: Doubling samples per update (12k→24k at 512 envs) reduces
    gradient noise, stabilizing learning. Old 8192-env runs had 196k samples
    and ep_len=480. With 512 envs at 24 rollouts, only 12k samples caused
    noisy updates and ep_len~100. 48 rollouts = 24k samples, partially
    compensating.
    [skrl_ppo_cfg.yaml]
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2026-03-14 autoresearch: increase entropy_loss_scale from 0.01 to 0.03
    Hypothesis: Triple exploration bonus prevents premature convergence to
    standing-still minimum. Higher entropy forces the policy to try more
    diverse joint configurations, potentially discovering stepping.
    [skrl_ppo_cfg.yaml]
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2026-03-15 autoresearch: restore config to post-EXP-246 state (revert 9 stale params + remove all_feet_penalty)
    [skrl_ppo_cfg.yaml]
2026-03-15 autoresearch: revert body_contact_threshold to 3.0 (stale EXP-251), baseline new gated forward_motion code
    [export_policy.py]
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2026-03-15 fix: address P2 bugs from code review
    - Bug 1: Clamp fallen forward reward to non-positive (prevents reward
    leaking into fallen poses via smooth posture gate). Test now passes.
    - Bug 3: Restore action_scale as numeric literal (0.5) so autoresearch.py
    regex rewriting works. The constant DEFAULT_ACTION_SCALE remains in
    common/policy_config.py for other consumers.
    - Bug 4: Export action_scale from training run manifest instead of
    hardcoding DEFAULT_ACTION_SCALE. Reads <run_dir>/manifest.json,
    falls back to default if not found.
    - Bug 2: False positive (schema already matches).
    - Bug 5: Latent risk (stance.yaml hasn't diverged yet), deferred.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
    [export_policy.py]
2026-03-15 docs: update memory docs for secret remediation + revert timesteps to 15000
    - Document Wi-Fi secret remediation in CONTEXT, EXPERIMENTS, OBSERVATIONS
    - Add password rotation reminder to NEXT_STEPS
    - Add session 48 desktop log
    - Revert timesteps 25000 -> 15000
    [skrl_ppo_cfg.yaml]
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2026-03-15 autoresearch: min_log_std -0.36 -> -1.0 to reduce action noise floor for stability
    [skrl_ppo_cfg.yaml]
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2026-03-15 fix: P2 bugs — delay auto-stop until validated + persist action_scale in manifest
    Bug 1 (harold.py): Move argument validation before auto-stopping an
    existing training process. Previously, `harold train` with invalid args
    (e.g. --iterations + --duration) would kill the running experiment before
    discovering the error, losing the in-flight data.
    Bug 2 (export_policy.py + harold.py): Include action_scale in the
    manifest's training_config when registering experiments. Update the
    export path to check training_config for action_scale, so non-default
    values are preserved through checkpoint export to ONNX deployment.
    [export_policy.py]
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2026-03-16 autoresearch: min_log_std -0.36 -> -2.0 to reduce action noise floor for stability
    [skrl_ppo_cfg.yaml]
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2026-03-17 autoresearch: revert seed 42->38 after EXP-353 seed sensitivity test
    Seed 42 found more stable but immobile optimum (vx=0.006 vs 0.048).
    Seed 38 produces the forward-stepping behavior needed for walking.
    [skrl_ppo_cfg.yaml]
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2026-03-17 autoresearch: orientation_threshold -0.6->-0.7 + timesteps 15000->25000 (EXP-355)
    Combination proposal: relax orientation to allow more dynamic motion,
    longer training to learn stability. Addresses ep_len bottleneck (160, need 300).
    Also restores joint_activity reward from EXP-354 revert.
    [skrl_ppo_cfg.yaml]
2026-03-17 autoresearch: upright_weight 3.0->4.0 for more stability (EXP-356)
    Hypothesis: stronger upright reward pressure will improve stability
    and episode survival while maintaining the stepping behavior from
    EXP-350. Addresses ep_len bottleneck (160, need 300).
    [skrl_ppo_cfg.yaml]
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2026-03-17 autoresearch: revert seed 42->38 after EXP-374
    Seed 42 backward motion confirmed. Return to seed=38 for EXP-372 config.
    [skrl_ppo_cfg.yaml]
2026-03-17 autoresearch: EXP-372 config at seed=100 for robustness (EXP-376)
    Test if the velocity-gated upright + stance_height=4.0 combo works
    with a different seed. seed=38 produced STEPPING, seed=42 failed.
    [skrl_ppo_cfg.yaml]
2026-03-17 autoresearch: revert seed 100->38 after EXP-376
    seed=38 most stable for EXP-372 combo. Reverting.
    [skrl_ppo_cfg.yaml]
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2026-03-17 autoresearch: revert entropy_loss_scale after EXP-377 FALLING
    entropy 0.02 too noisy. Reverting to 0.01.
    [skrl_ppo_cfg.yaml]
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2026-03-17 autoresearch: discount_factor 0.99->0.995 longer horizon (EXP-380)
    Higher discount = more weight on future rewards. May teach robot
    to step more carefully for longer survival instead of short-burst
    stepping that leads to falls.
    [skrl_ppo_cfg.yaml]
2026-03-17 autoresearch: revert discount_factor after EXP-380
    0.995 didn't beat EXP-372. Reverting to 0.99.
    [skrl_ppo_cfg.yaml]
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2026-03-18 autoresearch: full revert to baseline (code + config) after 28 DISCARDs
    Quadratic gate + motion rewards produced metric-gaming rocking, not walking.
    Starting fresh with baseline to try displacement-verified approach.
    [skrl_ppo_cfg.yaml]
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2026-03-19 autoresearch: EXP-437 revert un-reverted pitch/height penalties + longer training (25000 timesteps)
    Reverts pitch_penalty (-8.0) and height_floor_penalty (-5.0) from discarded
    EXP-434 that were never removed — contaminated EXP-435 and EXP-436.
    Also increases timesteps 15000->25000 to give policy more time to learn.
    [skrl_ppo_cfg.yaml]
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2026-03-19 autoresearch: EXP-466 min_log_std=-1.0 (tighter actions)
    Reduce minimum action std from 0.70 to 0.37. More precise leg control
    may reduce random tipping. Current floor is very high.
    [skrl_ppo_cfg.yaml]
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2026-03-19 autoresearch: session wrap-up — 30 experiments, 0 keeps
    Session 2026-03-19 explored: reward weights, code changes, PPO hyperparams,
    termination thresholds, training duration, seeds, command config.
    Key insights:
    - forward_motion=0 gives best ep_len (178, EXP-452)
    - tanh saturation improves upright (0.915, EXP-453)
    - upright_weight=5.0 causes crouching exploit (EXP-458)
    - Low stability rewards improve metrics but hurt survival (EXP-470)
    - Baseline vx=0.057 gives walk_score=45 IF ep_len>=300
    - The ONLY bottleneck is episode survival (~4.4 terminations/174 steps)
    - EXP-442-444 were contaminated by EXP-441 code changes (vx_gate+pitch)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
    [skrl_ppo_cfg.yaml]
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2026-03-19 autoresearch: EXP-491 revert rollouts=24, short duration at 16384 envs
    rollouts=8 (EXP-490) produced degenerate frozen pose. Temporal horizon
    too short (0.4s) for walking discovery. Reverting to rollouts=24 (1.2s
    horizon) which showed lunging/stepping in EXP-488. Trying longer training.
    [skrl_ppo_cfg.yaml]
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2026-03-20 autoresearch: EXP-498 entropy_loss_scale=0.02 (more exploration)
    All reward-axis changes on EXP-493 config failed to improve stepping.
    Try PPO axis: increase entropy from 0.01 to 0.02 to help policy
    explore more stable gaits instead of collapsing to forward pitch.
    [skrl_ppo_cfg.yaml]
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
